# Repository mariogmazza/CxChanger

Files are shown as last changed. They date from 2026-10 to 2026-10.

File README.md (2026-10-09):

# CxChanger

CxChanger is a low-cost FDM multi-material and multi-color printing solution. It switches between preheated hotend modules loaded with different filaments to reduce tool-change waiting time. The design aims to remain inexpensive, mechanically simple, and reliable. Tool changes are driven by the printhead's XY motion, and the docking mechanism is designed to be adaptable to other hotends by changing the hotend mounting hardware.

CxChanger printhead

CxChanger example

---

## Key Features

- **Automatic preheating:** Enable OrcaSlicer's Ooze Prevention feature and configure its preheat interval. OrcaSlicer can issue preheating commands before a material change. During the change, the old hotend is released and placed into its standby state while the next preheated hotend is picked up. If the next change is due soon, the next hotend can remain hot instead of cooling down.
- **Under-actuated tool-changing mechanism:** No dedicated powered lock actuator is required. The printhead's XY movement interacts with the dock to change hotends and open or close the filament idler.
- **Magnetic Maxwell kinematic coupling:** N52 magnets preload a Maxwell kinematic coupling. Three grooves made from locating pins are on the printhead side; three rounded locating pins on the removable hotend form the mating contact points. The three-point coupling constrains the tool's six degrees of freedom without over-constraint, helping it compensate for small manufacturing, assembly, wear, and thermal deviations.
- **Automatic nozzle-offset calibration:** A calibration fixture can measure each tool's XYZ offset relative to T0. Contact methods require a clean nozzle; non-contact eddy-current methods avoid that limitation. Recalibration is generally needed after initial assembly or after an event such as a tool crash, not before every print.
  - Contact calibration reference: https://github.com/Noisyfox/FoxChanger/tree/main/NozzleProbe
  - Non-contact eddy-current reference: https://oshwlab.com/cxg01/project_lbabffjk

## Hardware and Software Requirements

### Hardware

- **Printer:** In principle, any printer with an XY-moving printhead may be adaptable, including Voron 2.4, Voron Trident, and similar machines. This project provides printhead and basic dock designs; the dock mounts must be adapted to the frame and motion envelope of the target printer.
- **Controller:** Each removable hotend has a wired heater and thermistor. Spare mainboard outputs may support a small number of additional hotends. More tools may require an expansion board to add heater and thermistor interfaces: https://oshwlab.com/rayzark/project_qxihkkhj

### Software

- **Firmware:** Tool changes are implemented with Klipper macros. Use the klipper-toolchanger calibration extension if you want to use the supplied automatic nozzle-offset calibration macros: https://github.com/viesturz/klipper-toolchanger
- **Slicer:** OrcaSlicer is the documented slicer. Other slicers may be possible but are not covered here.

## System Overview

### Main assemblies

- **Permanent printhead:** All moving printhead components except the removable hotend module.
- **Removable hotend module:** Hotend, PTFE filament tube, heater, thermistor, and wiring.
- **Dock:** Stores each parked hotend, seals its nozzle to reduce ooze, and provides cooling for the parked tool. An open-frame printer can use a side-mounted centrifugal blower to cool the full dock array; an enclosed printer can use one axial fan per dock.

## Bill of Materials

### Printed-part version

- 6 × cylindrical locating pins, Ø1.5 × 5 mm, used to form the three grooves of the Maxwell coupling.
- 3 × rounded locating pins, Ø3 × 6 mm, per removable hotend, forming the mating kinematic contact points.
- 1 × internally threaded rounded pin, Ø5 × 20 mm, per dock, acting on the extruder lever.
- Ø6 × 4 mm N52 magnets: 3 per removable hotend, 1 per dock, and 3 on the permanent printhead.
- M3 × 6 mm countersunk screws.
- M3 × 25 mm screws.
- M3 × 8 mm screws.
- M3 × 10 mm screws.
- M3 × 12 mm screws.
- M3 × 14 mm screws.
- M3 × 20 mm screws.
- M2.5 × 16 mm screws.
- M2 × 8 mm screws.
- M3 heat-set inserts, 4 mm OD × 4 mm long (confirm the supplier's dimensional convention).
- HGX extruder gear set.
- 4020 blower fan.
- 2510 axial fan.
- Omron microswitch.
- 10 × 2 mm (width × thickness) self-adhesive, heat-resistant silicone strip.

### CNC version

Use the version-matched BOM supplied with the project. Do not combine the CNC parts, dock geometry, or toolchanger macros from different revisions without checking their interfaces.

## Installation and Configuration

### printer.cfg

Keep the motion, MCU, stepper-driver, heater, probe, and safety configuration that is already proven on your printer. Adapt the example instead of copying its board-specific pins unchanged.

1. Include toolchange.cfg and calibration.cfg.
2. Define an additional heater/thermistor section for each removable hotend, following the existing extruder1 pattern. The single physical extruder drive is shared; additional hotends are heater/sensor definitions rather than independent filament-drive motors. Wire heater and sensor inputs according to the actual controller.
3. The documented probing method uses a fixed microswitch. The tools are parked and the nozzle seals rest against high-temperature silicone during preheating. During leveling, the removable hotends remain docked so the fixed switch is the lowest sensing point. This configuration is specific to the documented implementation; other probe/leveling arrangements require an explicit integration.
4. Add dock-cooling fan configuration. Associate the relevant hotend/heatbreak cooling fans with every hotend whose temperature should keep the fan active.
5. Update print-start G-code so every hotend used by the sliced model is heated and primed before printing.
6. Update print-end G-code to call UNTOOL and turn off all hotend heaters so the machine finishes with the tool parked.

### toolchange.cfg

1. Include the toolchange macros. After the configuration loads, the UI should expose T0, T1, T2, T3, and UNTOOL for a four-tool setup. **Do not execute a tool-change macro before coordinates and the full motion path have been validated.** Incorrect coordinates can cause a collision.
2. Mount the docks and measure their coordinates mechanically:
   - Manually attach a hotend to the printhead.
   - Move the printhead to the intended dock side and align the first dock so the tool's hook screw passes cleanly through the dock opening.
   - Remove the tool and home the printer.
   - Reattach the tool and slowly jog to the same mechanical engagement point.
   - Record the machine coordinates and enter them as the T0 dock coordinates.
   - Nominal dock spacing is 30 mm. Derive the other dock positions from the pitch, then individually verify and correct each dock.
3. Test the motion path at a slow speed first. Keep your hand near the emergency stop and watch for misalignment.
4. Only increase speed after repeated cold and hot pickup/dropoff cycles work reliably.

### calibration.cfg

1. Install the calibration extension: https://github.com/viesturz/klipper-toolchanger
2. Home XYZ, level the bed/gantry, and mount the calibration fixture securely.
3. Pick up T0 and position its nozzle about 1 mm above the fixture center. Record the coordinates and enter the fixture location in calibration.cfg.
4. Define a separate safe calibration position outside the dock array and outside the path of all parked tools.
5. Calibrate T0 first, then the remaining tools. Depending on the installed extension version, the commands are TOOL_LOCATE_SENSOR and TOOL_CALIBRATE_TOOL_OFFSET; follow the extension's installed command names and verify the saved results.
6. Validate tool offsets with a test print before production.

### OrcaSlicer

Configure the printer's Start G-code, tool-change G-code, number of extruders, and tool-change retraction for the number of hotends actually installed. The following is a five-slot source example; remove unused tool parameters for a smaller build and do not configure T4 unless the hardware, heaters, and macros have been added.

**Start G-code example:**

    PRINT_START BED=[first_layer_bed_temperature] INITIAL_TOOL=[initial_tool] T0_TEMP={nozzle_temperature_initial_layer[0]} T0_USED={is_extruder_used[0]} T1_TEMP={nozzle_temperature_initial_layer[1]} T1_USED={is_extruder_used[1]} T2_TEMP={nozzle_temperature_initial_layer[2]} T2_USED={is_extruder_used[2]} T3_TEMP={nozzle_temperature_initial_layer[3]} T3_USED={is_extruder_used[3]} T4_TEMP={nozzle_temperature_initial_layer[4]} T4_USED={is_extruder_used[4]}

**Tool-change G-code example:**

    M104 S{nozzle_temperature[next_extruder]} T{next_extruder}
    T{next_extruder}

Enable the wipe tower and Ooze Prevention for initial validation. The original project suggests around 35 seconds as a starting preheat interval; tune it to the measured heat-up performance of your hotends. Coordinate slicer retraction with any pickup prime/retract configured in the macros to avoid stacking unintended extrusion moves.

## Build Notes and Critical Precautions

- Print structural parts in ABS using 4 walls and 60% infill, as specified by the project documentation.
- The HGX extruder spring requires more preload than a conventional arrangement because the compact lever geometry reduces mechanical advantage. Verify that the dock can still open the idler fully.
- For the documented TZ2.0 hotend arrangement, the project recommends removing the two heater-block retaining screws and using the side set screw for retention to reduce heat conduction. Verify this against the exact hotend revision before applying it.
- Install magnets to the depth and flushness shown in the matching CAD. Correct assembly should have the removable tool's rounded pins contacting the grooves on the printhead backing plate while the opposing magnets retain a small clearance. Check for rocking or backlash. If print accuracy degrades, inspect the locating pins and magnet retention; a loose magnet can migrate into contact with its mate and defeat the kinematic coupling.
- The tool's dock-hook screw should be a magnetic 12.9-grade steel socket-head screw. Ordinary 304 stainless steel may not be attracted properly by the dock magnet.
- The 30 mm dock pitch and sample coordinates are design references, not universal coordinates. Determine every dock position on the actual printer.

## Safety and Revision Notice

This repository includes example machine configuration. Heater pins, thermistor pins, probe pins, endstop logic, travel bounds, dock coordinates, and tool offsets are hardware- and frame-specific. Keep tool-change motion disabled until a complete manual dry-run and low-speed powered test pass. Never assume the software's saved tool state matches physical hardware after an E-stop or power loss.

This project is licensed under GPL-3.0. Preserve the original license and upstream attribution when redistributing modifications.

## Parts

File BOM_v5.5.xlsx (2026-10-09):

项目号 | 零件号 | 数量 | 价格 | 链接
HGX挤出齿轮套件 | 17 44双联齿轮 | 1 | 35.5 | https://item.taobao.com/item.htm?id=682175013983
 | 36齿挤出齿轮 | 2
 | 直径3长16圆柱销 | 2
 | 轴承外径6内径3厚2.5 | 4
 | 压簧 | 1
 | 直径3长24圆柱销 | 1
打印件 | 热端固定件 | 1
 | 停靠坞 | 数量根据自己需要来
 | 风道改 | 1
嘉立创拼版CNC | 顶部磁铁固定板 | 1 | 10 | 用上每个月两次的免费打样，加自己攻丝。不能自己攻丝的嘉立创1块钱攻一个（总共5个M3螺丝孔）
 | 弹簧撑板 | 1
 | 摆杆内（CNC） | 1
 | 摆杆内（CNC） | 1
 | 简化盖板 | 1
 | 打印头背板 | 1
 | 简化盖板 | 1
 | 铁氟龙管内径2外径4 | 热端固定件打印件内壁填充
 | 圆柱销直径1.5长5 | 用于构成麦克斯韦耦合定位的槽（×6） |  | https://detail.tmall.com/item.htm?id=1013104858939
 | 内螺纹圆头销M3外径5长18 | 装配于停靠坞上用于撑开挤出机摆臂（一个停靠坞1个） |  | https://detail.tmall.com/item.htm?id=864132087543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
 | 圆头销直径3长4 | 用于构成麦克斯韦耦合定位的球（一个热端3个） |  | https://detail.tmall.com/item.htm?id=868817943817
 | TZ2.0 | 数量根据自己需要来
 | N52磁铁直径6厚4 | 用于吸附热端模块到打印头上和停靠坞上（一个热端3个，一个停靠坞1个，打印头3个） |  | https://item.taobao.com/item.htm?id=968742198263
 | 2510风扇 | 1
 | 36圆饼步进电机 | 1
 | 微动开关 | 1
 | M4六角隔离柱10 | 2 |  | https://item.taobao.com/item.htm?abbucket=19&id=790190576194&ns=1&skuId=5961506598999&xxc=taobaoSearch
 | M4六角隔离柱14 | 1
 | M4带孔螺栓 | 1
 | 4020离心风扇 | 1
 | 杯头M3*8 | 2
 | M4螺母 | 1
 | 半圆头M3*22 | 7
 | 杯头M3*15 | 3
 | 杯头M2.5*14 | 2
 | M3螺母 | 5
 | 杯头M3*6 | 1
 | 杯头M3*10 | 3
 | 杯头M2*8 | 2
 | 停靠坞没有统一设计，这里不列举，螺丝种类自己判断

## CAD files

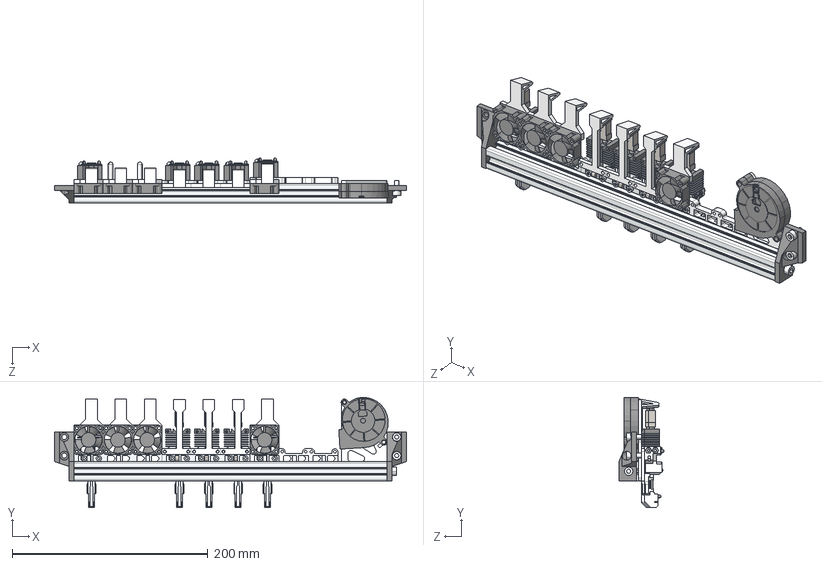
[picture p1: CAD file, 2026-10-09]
CAD/Dock_Assembly_v5.5.STEP
360.0 x 112.6 x 46.2 mm
LE-6-2020铝型材[LE-6-2020-B-OO-318]_LE-6-2020-B-OO-240
耐热硅胶垫 x 4
N52磁铁 6 4 x 18
热端停靠坞下置（CNC） x 2
停靠坞下置堵嘴 x 3
停靠坞下置堵嘴短 x 3
不锈钢内螺纹圆弧销 x 7
热端固定件 x 5
散热翅片_拓竹 x 5
喷嘴+喉管_拓竹 x 5
P1P陶瓷加热片 x 5
圆柱头螺栓_M3*10 x 10
耗材丝 x 5
圆头销 x 15
M3螺母 x 20
铁氟龙管 x 5
半圆头螺栓_M3*20 x 10
停靠坞横杆固定
圆柱头螺栓_M5*10 x 3
Mirror停靠坞横杆固定
Fan 3010 x 4
5015离心风扇
5015固定
沉头螺栓_M3*8 x 5
热端停靠坞下置（打印）
停靠坞下置堵嘴短（打印）

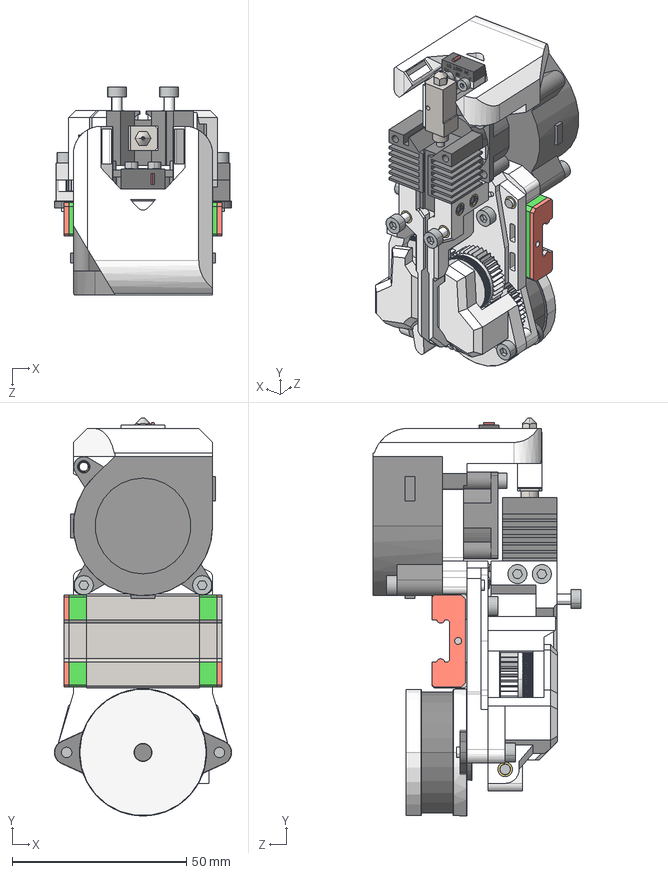
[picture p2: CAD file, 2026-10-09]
CAD/Printhead_Printed_v4.25.STEP
50.9 x 114.2 x 59.8 mm
新打印头背板（三叉戟）
17 44双联齿轮
36齿挤出齿轮 x 2
N52磁铁 6 4 x 6
36圆形步进电机
6mm Bearing[2] x 4
圆柱销 x 6
MGN12H
micro switch_Varsayılan
风道改
4020涡轮风扇
FAN DC12V 2510
摆杆改
热熔螺母M3 4 4 x 10
打印盖板
圆柱头螺栓_M2.5*16 x 2
圆柱头螺栓_M3*10 x 2
直径3长16圆柱销 x 2
垫圈_3.2*6*0.5
热端固定件
散热翅片_拓竹
喷嘴+喉管_拓竹
P1P陶瓷加热片
圆头销 x 3
圆柱头螺栓_M3*20 x 2
圆柱头螺栓_M3*8 x 3
耗材丝
打印垫块
圆柱头螺栓_M3*25 x 2
spring^thumbscrew
圆柱头螺栓_M3*22
圆柱头螺栓_M2*8 x 2
圆柱头螺栓_M3*14 x 2
直径3长24圆柱销

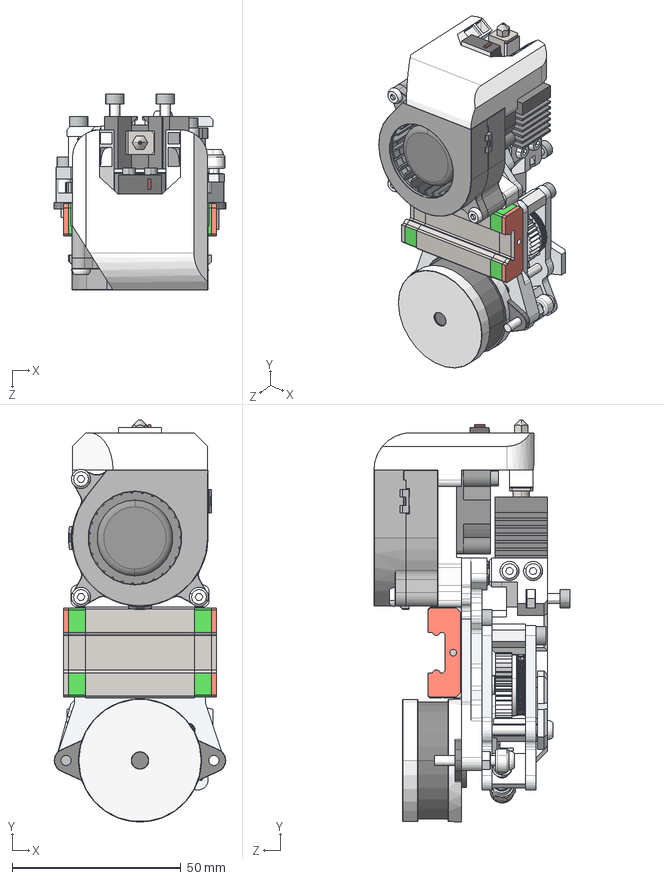
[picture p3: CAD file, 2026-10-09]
CAD/Printhead_v5.5_Fan_Duct_Orientation_Corrected.STEP
50.9 x 119.2 x 58.2 mm
17 44双联齿轮
36齿挤出齿轮 x 2
直径3长16圆柱销 x 2
圆柱销外径1.5长5 x 6
轴承外径6内径3厚2.5 x 4
N52磁铁 6 4 x 6
风道改
36圆饼步进电机
2510风扇
热端固定件
散热翅片_拓竹
喷嘴+喉管_拓竹
P1P陶瓷加热片
圆柱头螺栓_M3*10 x 4
耗材丝
圆头销外径3长4 x 3
M3螺母 x 5
铁氟龙管
半圆头螺栓_M3*22 x 7
M4带孔螺栓
压簧
百瑞特防滑螺母_M4
顶部磁铁固定板
弹簧撑板
圆柱头螺栓_M3*15 x 3
圆柱头螺栓_M2.5*14 x 2
micro switch_Varsayılan
直径3长24圆柱销
M4六角隔离柱10 x 2
M4六角隔离柱14
简化盖板_简化盖板左
简化盖板_简化盖板右
4020离心风扇_По умолчанию
摆杆内（CNC）
摆杆内（CNC）_外
圆柱头螺栓_M2*8 x 2
打印头背板cnc（三叉戟）
MGN12H
圆柱头螺栓_M3*6

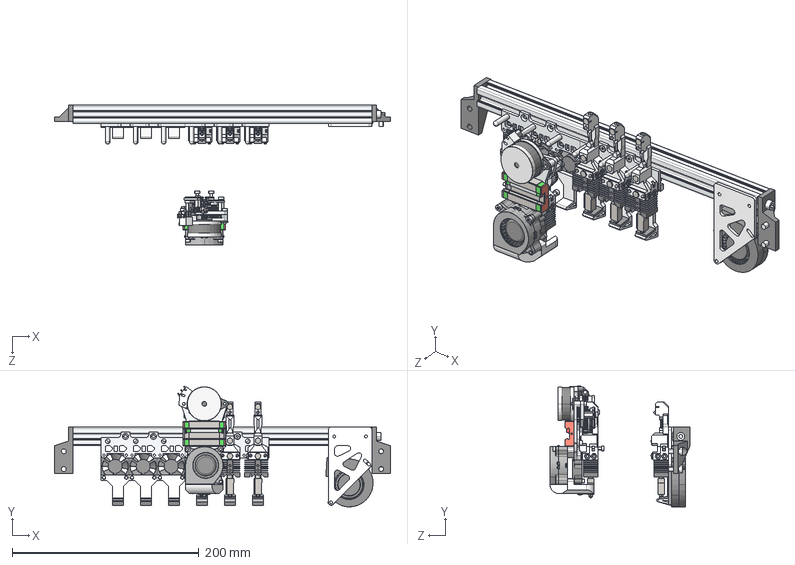
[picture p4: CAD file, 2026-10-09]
CAD/Printhead_v5.1.STEP
360.0 x 129.4 x 150.3 mm
17 44双联齿轮
圆柱头螺栓_M3*10 x 10
打印头背板cnc（三叉戟）
36齿挤出齿轮 x 2
直径3长16圆柱销 x 2
圆柱销 x 6
MGN12H
6mm Bearing[2] x 4
圆柱头螺栓_M3*8
隔离柱外径5内径3长10
N52磁铁 6 4 x 18
风道改
36圆形步进电机
FAN DC12V 2510 x 2
热端固定件 x 4
散热翅片_拓竹 x 4
喷嘴+喉管_拓竹 x 4
P1P陶瓷加热片 x 4
耗材丝 x 4
圆头销 x 12
M3螺母 x 16
铁氟龙管 x 4
半圆头螺栓_M3*20 x 9
M4带孔螺栓
百瑞特防滑螺母_M3
spring^thumbscrew
百瑞特防滑螺母_M4
顶部磁铁固定板
弹簧撑板
摆杆外（CNC）
圆柱头螺栓_M3*14
圆柱头螺栓_M3*22 x 2
圆柱头螺栓_M2.5*16 x 2
micro switch_Varsayılan x 2
mgn9h
耗材检测固定
圆柱头螺栓_M2*15
半圆头螺栓_M3*16
直径3长24圆柱销
摆杆内（CNC）
M4六角隔离柱10
M4六角隔离柱14
简化盖板_简化盖板左
简化盖板_简化盖板右
圆柱头螺栓_M3*15
4020TB_По умолчанию x 2
半圆头螺栓_M3*22
半圆头螺栓_M3*14
LE-6-2020铝型材[LE-6-2020-B-OO-318]_LE-6-2020-B-OO-240
耐热硅胶垫 x 3
热端停靠坞下置（CNC） x 2
停靠坞下置堵嘴 x 3
停靠坞下置堵嘴短 x 3
不锈钢内螺纹圆弧销 x 6
停靠坞横杆固定
圆柱头螺栓_M5*10 x 3
Mirror停靠坞横杆固定
Fan 3010 x 3
5015离心风扇
5015固定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

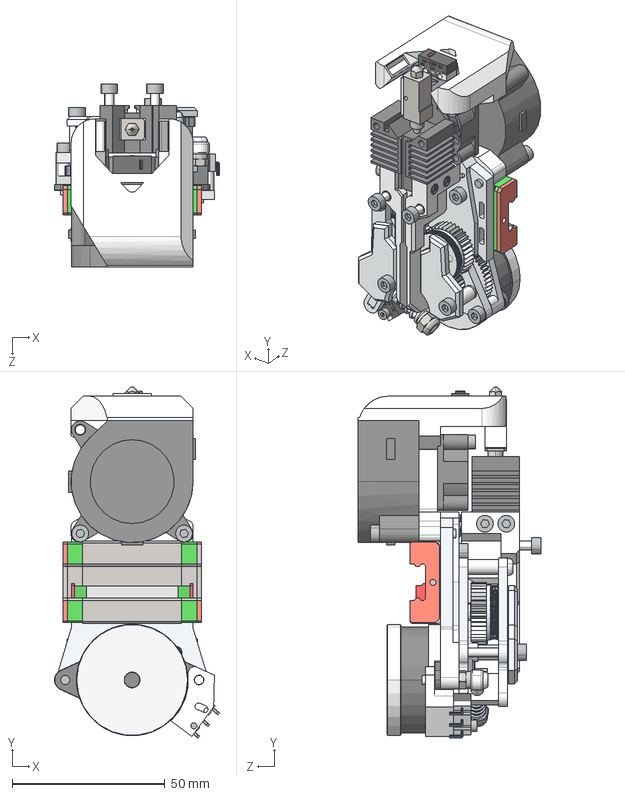
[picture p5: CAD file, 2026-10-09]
CAD/Printhead_CNC_v4.25.STEP
54.1 x 115.0 x 59.8 mm
17 44双联齿轮
圆柱头螺栓_M3*10 x 2
打印头背板cnc（三叉戟）
36齿挤出齿轮 x 2
直径3长16圆柱销 x 2
圆柱销 x 6
MGN12H
6mm Bearing[2] x 4
圆柱头螺栓_M3*8 x 3
隔离柱外径5内径3长10 x 2
隔离柱外径5内径3长8
N52磁铁 6 4 x 6
风道改
36圆形步进电机
4020涡轮风扇
FAN DC12V 2510
热端固定件
热熔螺母M3 4 4 x 4
散热翅片_拓竹
喷嘴+喉管_拓竹
P1P陶瓷加热片
圆头销 x 3
圆柱头螺栓_M3*20 x 2
耗材丝
M4带孔螺栓
百瑞特防滑螺母_M3
spring^thumbscrew
百瑞特防滑螺母_M4
顶部磁铁固定板
cnc盖板右
弹簧撑板
摆杆外（CNC）
cnc盖板左
圆柱头螺栓_M3*14 x 2
圆柱头螺栓_M3*25 x 3
圆柱头螺栓_M2.5*16 x 2
micro switch_Varsayılan x 2
mgn9h
耗材检测固定
圆柱头螺栓_M2*15
半圆头螺栓_M3*16
直径3长24圆柱销
摆杆内（CNC）
半圆头螺栓_M3*20

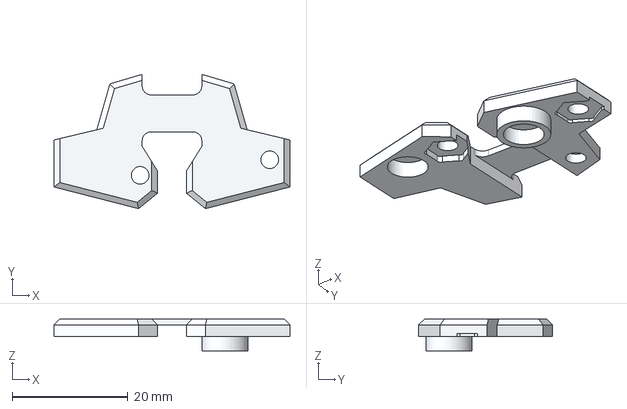
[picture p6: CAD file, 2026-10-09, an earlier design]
Legacy_Assembly_v5.5_v5.1/Cover_Plate_PB1_v5.1.step
40.8 x 23.2 x 5.50 mm

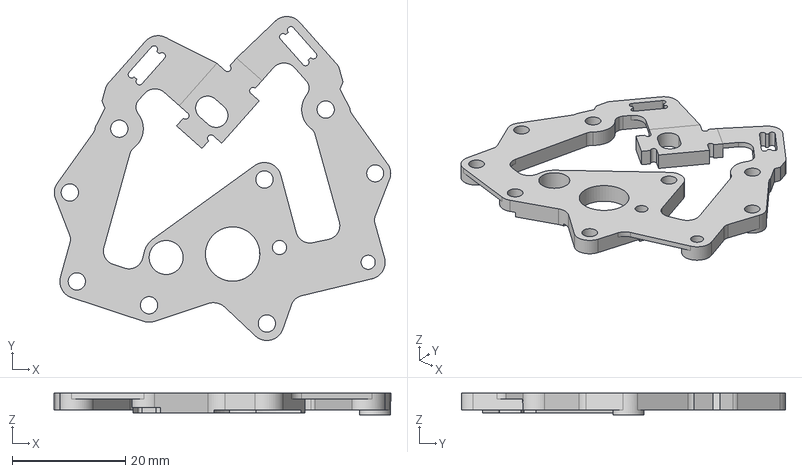
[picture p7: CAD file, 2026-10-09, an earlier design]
Legacy_Assembly_v5.5_v5.1/Lever_Arm_PB2_Thread_Recognizable_v5.1.step
59.4 x 57.2 x 3.80 mm
实体1 (2)
实体1 (4)
实体1 (1)
实体1 (3)

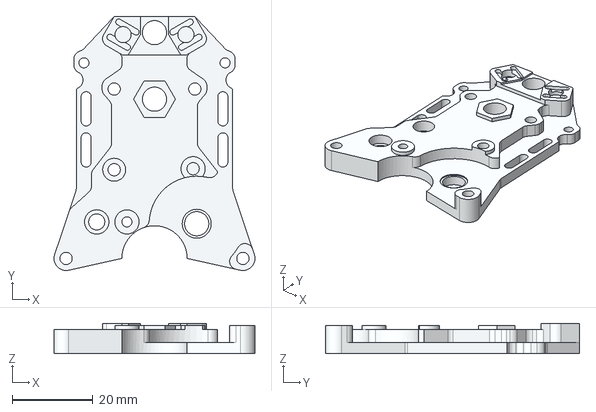
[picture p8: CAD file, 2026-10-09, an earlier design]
Legacy_Assembly_v5.5_v5.1/Backplate_2.5mm_Belt_Groove_v5.1.step
49.8 x 63.0 x 7.50 mm

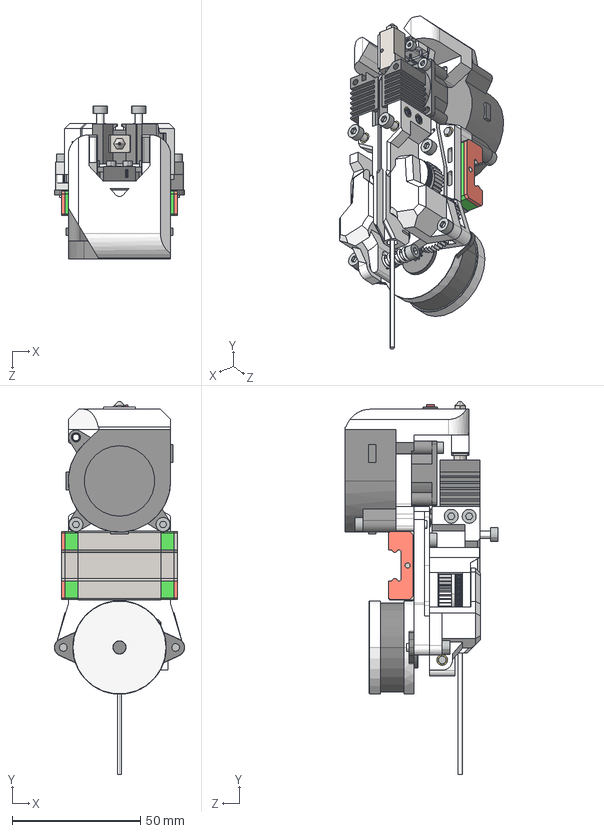
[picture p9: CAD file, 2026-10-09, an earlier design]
CAD/Printhead_Printed_v4.24.STEP
50.9 x 145.6 x 59.8 mm
新打印头背板（三叉戟）
17 44双联齿轮
36齿挤出齿轮 x 2
N52磁铁 6 4 x 6
36圆形步进电机
6mm Bearing[2] x 4
圆柱销 x 6
MGN12H
micro switch_Varsayılan
风道改
4020涡轮风扇
FAN DC12V 2510
摆杆改
热熔螺母M3 4 4 x 10
打印盖板
圆柱头螺栓_M2.5*16 x 2
圆柱头螺栓_M3*10 x 2
直径3长16圆柱销 x 2
垫圈_3.2*6*0.5
热端固定件
散热翅片_拓竹
喷嘴+喉管_拓竹
P1P陶瓷加热片
圆头销 x 3
圆柱头螺栓_M3*20 x 2
圆柱头螺栓_M3*8 x 3
耗材丝
打印垫块
圆柱头螺栓_M3*25 x 2
spring^thumbscrew
圆柱头螺栓_M3*22
圆柱头螺栓_M2*8 x 2
圆柱头螺栓_M3*14 x 2
直径3长24圆柱销

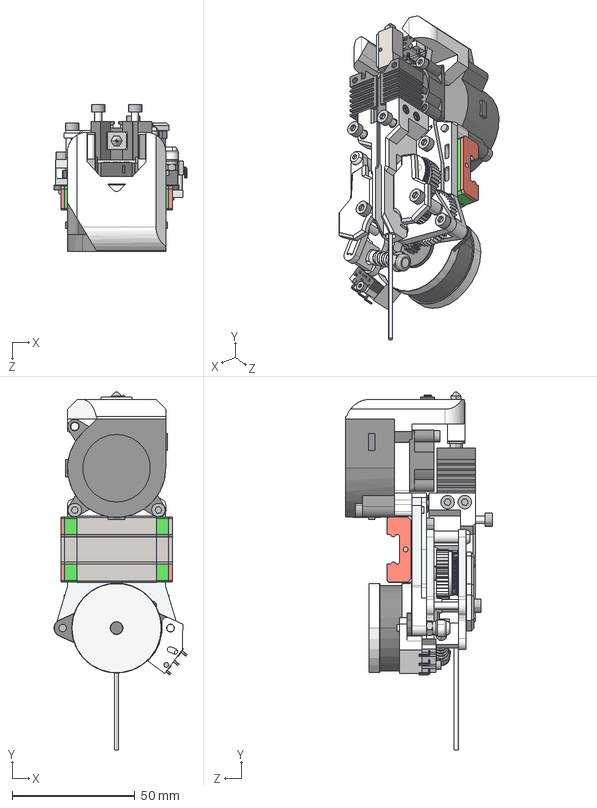
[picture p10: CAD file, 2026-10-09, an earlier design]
CAD/Printhead_CNC_v4.24.STEP
54.1 x 145.6 x 59.8 mm
17 44双联齿轮
圆柱头螺栓_M3*10 x 2
打印头背板cnc（三叉戟）
36齿挤出齿轮 x 2
直径3长16圆柱销 x 2
圆柱销 x 6
MGN12H
6mm Bearing[2] x 4
圆柱头螺栓_M3*8 x 3
隔离柱外径5内径3长10 x 2
隔离柱外径5内径3长8
N52磁铁 6 4 x 6
风道改
36圆形步进电机
4020涡轮风扇
FAN DC12V 2510
热端固定件
热熔螺母M3 4 4 x 4
散热翅片_拓竹
喷嘴+喉管_拓竹
P1P陶瓷加热片
圆头销 x 3
圆柱头螺栓_M3*20 x 2
耗材丝
M4带孔螺栓
百瑞特防滑螺母_M3
spring^thumbscrew
百瑞特防滑螺母_M4
顶部磁铁固定板
cnc盖板右
弹簧撑板
摆杆外（CNC）
cnc盖板左
圆柱头螺栓_M3*14 x 2
圆柱头螺栓_M3*25 x 3
圆柱头螺栓_M2.5*16 x 2
micro switch_Varsayılan x 2
耗材检测固定
圆柱头螺栓_M2*15
半圆头螺栓_M3*16
直径3长24圆柱销
摆杆内（CNC）
半圆头螺栓_M3*20

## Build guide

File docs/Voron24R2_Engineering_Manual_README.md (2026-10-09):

# CxChanger Voron 2.4 R2 Engineering Manual

The complete illustrated 38-page PDF is supplied in the accompanying download bundle. It covers mechanical assembly, BOM/prerequisites, Maxwell coupling, dock coordinates and XY paths, wiring architecture, Klipper integration, calibration, OrcaSlicer, commissioning, troubleshooting and maintenance.

**Important:** PDF/manual content is an engineering adaptation, not an official Voron document. Heater/sensor pins and dock coordinates must be measured on the target machine. Motion must remain disabled until the physical path is validated. See `patches/UPSTREAM_REVIEW_AND_CHANGES.md` for the reviewed issues and changes.

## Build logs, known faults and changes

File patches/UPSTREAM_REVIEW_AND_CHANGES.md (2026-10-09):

# CxChanger review notes (2026-10-09)

Upstream sample defines four tools (T0-T3), nominal 30 mm dock pitch, sample coordinates T0 (232,-20), T1 (202,-20), T2 (172,-20), T3 (142,-20), and dock path offsets X=-3 mm, Y dodge=14 mm, safe Y=30 mm. These are author-machine values, not universal Voron coordinates.

Key proposed fixes:
- Add a fail-closed `motion_enabled: 0` commissioning gate.
- Check XYZ homed and tool index before any dock movement.
- Change `RESTORE_GCODE_STATE ... MOVE=0` to `MOVE=1` to physically return to saved XYZ, only after verifying the return path is collision-free.
- Reduce commissioning speeds/acceleration and leave prime/retract at zero until tuned with slicer.
- Do not blindly trust saved active tool state after restart/E-stop.
- Use `last_x_result`, `last_y_result`, `last_z_result` only if the installed calibration extension version exposes them.
- Upstream tool sensor comment mentions `expander:PA9` but active sample pin is `PC14`; verify actual board pin.
- Do not guess heater/thermistor/probe/CAN/fan pins for a Voron.

Do not mark production-ready until dock coordinates, negative Y limits, full return route, wiring, switch polarity and repeated hot/cold pickup cycles have been physically validated.

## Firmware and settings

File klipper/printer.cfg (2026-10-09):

[respond]          # ： M118 
[pause_resume]  # English note: see README.md for parameter guidance.
[display_status]  # English note: see README.md for parameter guidance.
[virtual_sdcard]
path: /usr/share/printer_data/gcodes

[gcode_macro PAUSE]
rename_existing: BASE_PAUSE
gcode:
    # ----- English note: refer to README.md for configuration guidance.
    {% set z_hop = 5.0 %}           ;  (mm)
    {% set x_park = 10.0 %}         ;  X 
    {% set y_park = 10.0 %}         ;  Y 
    {% set retract_len = 0 %}     ;  (mm)
    
    # 1. English note: refer to README.md for configuration guidance.
    SAVE_GCODE_STATE NAME=PAUSE_state
    
    # 2. English note: refer to README.md for configuration guidance.
    BASE_PAUSE
    
    # 3. English note: refer to README.md for configuration guidance.
    {% if printer.extruder.can_extrude %}
        M83                          ; 
        G1 E-{retract_len} F2100     ; 
    {% endif %}
    
    # 4. English note: refer to README.md for configuration guidance.
    {% set max_z = printer.toolhead.axis_maximum.z|float %}
    {% set cur_z = printer.toolhead.position.z|float %}
    {% if cur_z < (max_z - z_hop) %}
        {% set z_safe = z_hop %}
    {% else %}
        {% set z_safe = max_z - cur_z %}
    {% endif %}

    G91                              ; 
    G1 Z{z_safe} F900                ;  Z ，
    
    # 5. English note: refer to README.md for configuration guidance.
    G90                              ; 
    G1 X{x_park} Y{y_park} F18000    ; 
    
    M118 [System] Parked safely; waiting for user intervention...

[gcode_macro RESUME]
rename_existing: BASE_RESUME
gcode:
    {% set retract_len = 0 %}      ;  PAUSE 
    
    # 1. English note: refer to README.md for configuration guidance.
    {% if printer.extruder.can_extrude %}
        M83
        G1 E{retract_len} F2100      ; 
    {% endif %}
    
    # 2. English note: refer to README.md for configuration guidance.
    # MOVE=1 English note: refer to README.md for configuration guidance.
    RESTORE_GCODE_STATE NAME=PAUSE_state MOVE=1 MOVE_SPEED=150
    
    M118 [System] Preparing to resume printing...
    BASE_RESUME
    
[gcode_macro CANCEL_PRINT]
description: Cancel the actual running print
rename_existing: CANCEL_PRINT_BASE
gcode:
  TURN_OFF_HEATERS
  CANCEL_PRINT_BASE
  G91
  G1 Z10 F600 ; 10mm
  UNTOOL
  M106 S0
[force_move]
enable_force_move: True
#####################################################################
#                               English note: refer to README.md for configuration guidance.
#####################################################################
[include toolchange.cfg]
[include calibration.cfg]
#[include idm.cfg]
#####################################################################
#                               English note: refer to README.md for configuration guidance.
#####################################################################
[mcu]
serial:/dev/serial/by-id/usb-Klipper_stm32f407xx_36003D001650334636343620-if00



#[mcu host]
#serial: /tmp/klipper_host_mcu

#####################################################################
#                            English note: refer to README.md for configuration guidance.
#####################################################################
#[mcu expander]
# English note: refer to README.md for configuration guidance.
#serial: /dev/serial/by-id/usb-Klipper_stm32f072xb_3F0035000357465036383420-if00 
#####################################################################
#                            English note: refer to README.md for configuration guidance.
#####################################################################
[printer]  # English note: see README.md for parameter guidance.
kinematics: corexy  # English note: see README.md for parameter guidance.
max_velocity: 400  # English note: see README.md for parameter guidance.
max_accel: 20000  # English note: see README.md for parameter guidance.
max_z_velocity: 30  # English note: see README.md for parameter guidance.
max_z_accel: 300  # English note: see README.md for parameter guidance.
square_corner_velocity: 5.0  # English note: see README.md for parameter guidance.
#####################################################################
#                             English note: refer to README.md for configuration guidance.
#####################################################################
[temperature_sensor MCU]    
sensor_type: temperature_mcu   

[temperature_sensor FLY-Pi]
sensor_type: temperature_host
#####################################################################
#             X/YEnglish note: refer to README.md for configuration guidance.
#####################################################################
#   B Motor ---- Motor A 
#   |                  |
#   |------English note: refer to README.md for configuration guidance.
#   |                  |
#   |                  |
#          English note: refer to README.md for configuration guidance.
#####################################################################
#                          X English note: refer to README.md for configuration guidance.
#####################################################################
## XEnglish note: refer to README.md for configuration guidance.
[stepper_x]
step_pin: PB9  # English note: see README.md for parameter guidance.
dir_pin: PE0  # English note: see README.md for parameter guidance.
enable_pin: !PE1  # English note: see README.md for parameter guidance.
rotation_distance: 40  # English note: see README.md for parameter guidance.
microsteps: 32  # English note: see README.md for parameter guidance.
full_steps_per_rotation: 200  # English note: see README.md for parameter guidance.
endstop_pin: PC3  # English note: see README.md for parameter guidance.
###English note: refer to README.md for configuration guidance.
position_min: -5  # English note: see README.md for parameter guidance.
position_endstop: 240  # English note: see README.md for parameter guidance.
position_max: 240  # English note: see README.md for parameter guidance.
homing_speed: 80  # English note: see README.md for parameter guidance.
homing_retract_dist: 0  # English note: see README.md for parameter guidance.
#--------------------------------------------------------------------
##  English note: refer to README.md for configuration guidance.
[tmc2209 stepper_x]  # English note: see README.md for parameter guidance.
uart_pin: PG13  # English note: see README.md for parameter guidance.
interpolate: False  # English note: see README.md for parameter guidance.
run_current: 1.1  # English note: see README.md for parameter guidance.
sense_resistor: 0.110  # English note: see README.md for parameter guidance.
#####################################################################
#                       y English note: refer to README.md for configuration guidance.
#####################################################################
## YEnglish note: refer to README.md for configuration guidance.
[stepper_y]
step_pin: PB8  # English note: see README.md for parameter guidance.
dir_pin: PG11  # English note: see README.md for parameter guidance.
enable_pin: !PG12  # English note: see README.md for parameter guidance.
rotation_distance: 40  # English note: see README.md for parameter guidance.
microsteps: 32  # English note: see README.md for parameter guidance.
full_steps_per_rotation: 200  # English note: see README.md for parameter guidance.
endstop_pin: PC2  # English note: see README.md for parameter guidance.
###English note: refer to README.md for configuration guidance.
position_min: -33  # English note: see README.md for parameter guidance.
position_endstop: 230  # English note: see README.md for parameter guidance.
position_max: 230  # English note: see README.md for parameter guidance.
homing_speed: 80  # English note: see README.md for parameter guidance.
homing_retract_dist: 0  # English note: see README.md for parameter guidance.
#--------------------------------------------------------------------
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

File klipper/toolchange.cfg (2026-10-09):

# CxChanger - safer four-tool Klipper macro adaptation
# Based on ers-ye/cxchanger/klipper/toolchange.cfg (reviewed 2026-10-09).
# Board pins and dock coordinates are machine-specific. Motion is disabled by default.

[save_variables]
filename: ~/printer_data/config/myvariables.cfg

# Never blindly restore a saved mounted-tool state after power loss or manual removal.
[delayed_gcode CX_INITIALIZE_TOOL_STATE]
initial_duration: 0.2
gcode:
    SET_GCODE_VARIABLE MACRO=_tool_status VARIABLE=current_tool VALUE=-1
    SET_FILAMENT_SENSOR SENSOR=tool_sensor ENABLE=0
    M118 [CxChanger] Startup state set to -1; verify physical tool state before printing.

# EXAMPLE PIN ONLY. Upstream active pin is PC14 although one comment mentions expander:PA9.
# Replace PC14 with the actual pin/polarity for your controller before use.
[filament_switch_sensor tool_sensor]
switch_pin: PC14
pause_on_runout: False
runout_gcode:
    {% set cfg = printer["gcode_macro _toolchanger_cfg"] %}
    {% if cfg.enable_sensor_check|int == 1 %}
        { action_respond_info("[CxChanger] Filament/runout sensor event; pausing.") }
        PAUSE
    {% else %}
        M118 [CxChanger] Sensor event ignored because enable_sensor_check=0.
    {% endif %}
insert_gcode:
    { action_respond_info("[CxChanger] Filament detected/inserted.") }

# Central settings. These dock centers are upstream sample values, not universal coordinates.
[gcode_macro _toolchanger_cfg]
description: CxChanger configuration variables
variable_motion_enabled: 0
variable_tool_count: 4
# The upstream mechanism is XY-actuated. Keep Z hop at 0 unless selected CAD explicitly allows it.
variable_z_hop: 0.0
variable_feed_z: 600                  # mm/min
variable_feed_fast: 3600              # mm/min: 60 mm/s conservative starting profile
variable_feed_slow: 900               # mm/min: 15 mm/s engagement test speed
variable_return_speed: 80             # mm/s for RESTORE_GCODE_STATE MOVE=1
variable_accel_toolchange: 1500       # mm/s^2; reduce further for first tests
variable_dock_shift_x: -3.0           # mm; mechanical HGX lever release/clamp motion
variable_dock_dodge_y: 14.0           # mm; Y withdrawal/approach offset
variable_dock_safe_y: 30.0            # mm; entry/exit clearance

# Upstream example coordinates - replace after physical measurement.
variable_t0_dock_x: 232.0
variable_t0_dock_y: -20.0
variable_t1_dock_x: 202.0
variable_t1_dock_y: -20.0
variable_t2_dock_x: 172.0
variable_t2_dock_y: -20.0
variable_t3_dock_x: 142.0
variable_t3_dock_y: -20.0

# Avoid stacking unknown purge/retraction during commissioning.
variable_pickup_retract_len: 0.0
variable_swap_retract_len: 0.0
variable_swap_prime_len: 0.0
variable_swap_retract_spd: 600.0     # mm/min
variable_enable_sensor_check: 0
gcode:
    # Configuration storage only.

[gcode_macro _tool_status]
variable_current_tool: -1
gcode:
    # Runtime state only; verify physical state after restart or interruption.

[gcode_macro T0]
description: Pick up T0 (motion requires motion_enabled=1)
gcode: change_tool T=0
[gcode_macro T1]
description: Pick up T1 (motion requires motion_enabled=1)
gcode: change_tool T=1
[gcode_macro T2]
description: Pick up T2 (motion requires motion_enabled=1)
gcode: change_tool T=2
[gcode_macro T3]
description: Pick up T3 (motion requires motion_enabled=1)
gcode: change_tool T=3
[gcode_macro UNTOOL]
description: Return current tool to its dock (motion requires motion_enabled=1)
gcode: change_tool T=-1

# Use only after visually confirming what is physically attached/parked.
[gcode_macro CX_RECONCILE_STATE]
description: Reconcile software tool state after restart/E-stop; inspect hardware first
gcode:
    {% set t = params.TOOL|default(-1)|int %}
    {% set cfg = printer["gcode_macro _toolchanger_cfg"] %}
    {% if t < -1 or t >= cfg.tool_count|int %}
        { action_raise_error("CX_RECONCILE_STATE supports TOOL=-1 or TOOL=0..3.") }
    {% else %}
        SET_GCODE_VARIABLE MACRO=_tool_status VARIABLE=current_tool VALUE={t}
        SAVE_VARIABLE VARIABLE=current_tool VALUE={t}
        M118 [CxChanger] Software state set to {t}; confirm this matches physical hardware.
    {% endif %}

[gcode_macro _release_tool]
description: Low-level release path; only call from change_tool
gcode:
    {% set cfg = printer["gcode_macro _toolchanger_cfg"] %}
    {% set tool = params.TOOL|int %}
    {% set prefix = "t" ~ tool %}
    {% set active_extruder = printer.toolhead.extruder %}
    {% set dock_x = cfg[prefix ~ "_dock_x"]|float %}
    {% set dock_y = cfg[prefix ~ "_dock_y"]|float %}
    {% set shift_x = cfg.dock_shift_x|float %}
    {% set dodge_y = cfg.dock_dodge_y|float %}
    {% set safe_y = cfg.dock_safe_y|float %}
    {% set cur_temp = printer[active_extruder].temperature|float %}
    {% set min_temp = printer.configfile.settings[active_extruder].min_extrude_temp|default(170)|float %}
    M118 [CxChanger] Releasing T{tool}
    {% if cfg.swap_retract_len|float > 0 and cur_temp >= min_temp %}
        M83
        G1 E-{cfg.swap_retract_len} F{cfg.swap_retract_spd}
    {% endif %}
    G90
    G0 X{dock_x} Y{dock_y + safe_y} F{cfg.feed_fast}
    G0 X{dock_x} Y{dock_y} F{cfg.feed_fast}
    G0 X{dock_x + shift_x} Y{dock_y} F{cfg.feed_slow}
    G0 X{dock_x + shift_x} Y{dock_y + dodge_y} F{cfg.feed_slow}
    G0 X{dock_x} Y{dock_y + dodge_y} F{cfg.feed_slow}
    G0 X{dock_x} Y{dock_y + safe_y} F{cfg.feed_fast}
    M400

[gcode_macro _pickup_tool]
description: Low-level pickup path; only call from change_tool
gcode:
    {% set cfg = printer["gcode_macro _toolchanger_cfg"] %}
    {% set tool = params.TOOL|int %}
    {% set prefix = "t" ~ tool %}
    {% set current_heater = "extruder" if tool == 0 else ("extruder" ~ tool) %}
    {% set dock_x = cfg[prefix ~ "_dock_x"]|float %}
    {% set dock_y = cfg[prefix ~ "_dock_y"]|float %}
    {% set shift_x = cfg.dock_shift_x|float %}
    {% set dodge_y = cfg.dock_dodge_y|float %}
    {% set safe_y = cfg.dock_safe_y|float %}
    {% set cur_temp = printer[current_heater].temperature|float %}
    {% set min_temp = printer.configfile.settings[current_heater].min_extrude_temp|default(170)|float %}
    M118 [CxChanger] Picking up T{tool}
    G90
    G0 X{dock_x} Y{dock_y + safe_y} F{cfg.feed_fast}
    G0 X{dock_x} Y{dock_y + dodge_y} F{cfg.feed_fast}
    G0 X{dock_x + shift_x} Y{dock_y + dodge_y} F{cfg.feed_slow}
    G0 X{dock_x + shift_x} Y{dock_y} F{cfg.feed_slow}
    G0 X{dock_x} Y{dock_y} F{cfg.feed_slow}
    {% if cur_temp >= min_temp and cfg.swap_prime_len|float > 0 %}
        M83
        G1 E{cfg.swap_prime_len} F{cfg.swap_retract_spd}
    {% endif %}
    {% if cur_temp >= min_temp and cfg.pickup_retract_len|float > 0 %}
        M83
        G1 E-{cfg.pickup_retract_len} F{cfg.swap_retract_spd}
    {% endif %}
    G0 X{dock_x} Y{dock_y + safe_y} F{cfg.feed_fast}
    M400

[gcode_macro _VERIFY_TOOL_AND_ENABLE_SENSOR]
description: Optional filament/runout-based pickup confirmation
gcode:
    {% set new_tool = params.NEW_TOOL|int %}
    {% set cfg = printer["gcode_macro _toolchanger_cfg"] %}
    {% if cfg.enable_sensor_check|int == 0 %}
        SET_FILAMENT_SENSOR SENSOR=tool_sensor ENABLE=0
        SAVE_VARIABLE VARIABLE=current_tool VALUE={new_tool}
        M118 [CxChanger] Sensor check disabled; visual coupling verification remains required.
    {% else %}
        {% set has_filament = printer["filament_switch_sensor tool_sensor"].filament_detected %}
        {% if has_filament %}
            SET_FILAMENT_SENSOR SENSOR=tool_sensor ENABLE=1
            SAVE_VARIABLE VARIABLE=current_tool VALUE={new_tool}
            {% set svv = printer.save_variables.variables %}
            {% set n = svv.total_tool_changes|default(0)|int + 1 %}
            SAVE_VARIABLE VARIABLE=total_tool_changes VALUE={n}
            M118 [CxChanger] Sensor indicates filament present; change recorded.
        {% else %}
            SET_FILAMENT_SENSOR SENSOR=tool_sensor ENABLE=0
            { action_respond_info("CxChanger pickup is unverified (or filament is absent). Inspect physically before resuming.") }
            PAUSE
        {% endif %}
    {% endif %}
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

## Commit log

2026-10-09 Harden CxChanger toolchange state and commissioning safety
    [toolchange.cfg]
2026-10-09 Add guarded tool calibration workflow and current result fields
    [calibration.cfg]
2026-10-09 Add Voron integration template with board-specific placeholders
2026-10-09 Replace non-English printer.cfg comments and messages with English
    [printer.cfg]
2026-10-09 Rename remaining non-English CAD and BOM paths
    [BOM_v5.5.xlsx, Backplate_2.5mm_Belt_Groove_v5.1.step, Cover_Plate_PB1_v5.1.step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]
